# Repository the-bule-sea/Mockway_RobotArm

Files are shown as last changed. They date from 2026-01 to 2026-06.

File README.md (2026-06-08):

<div align="center">
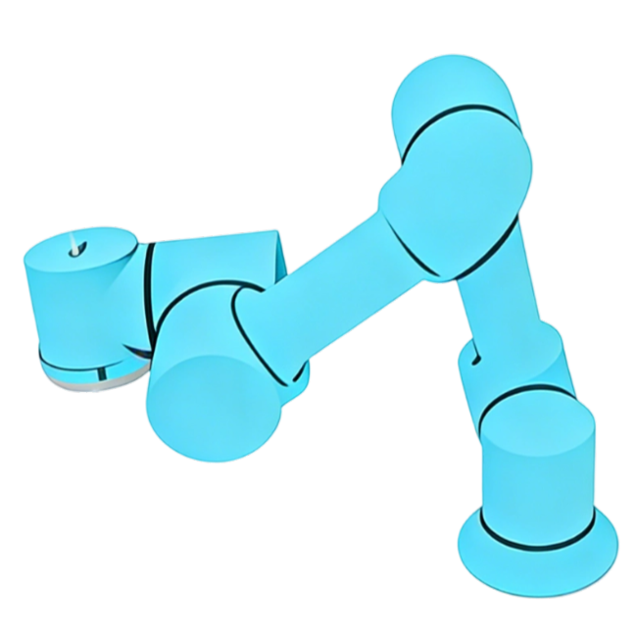
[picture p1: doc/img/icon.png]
  

  # 牧卫机器人

  开源六轴协作机械臂系统，包含机械结构、电路和软件

</div>

**中文 | [English](README_EN.md)**

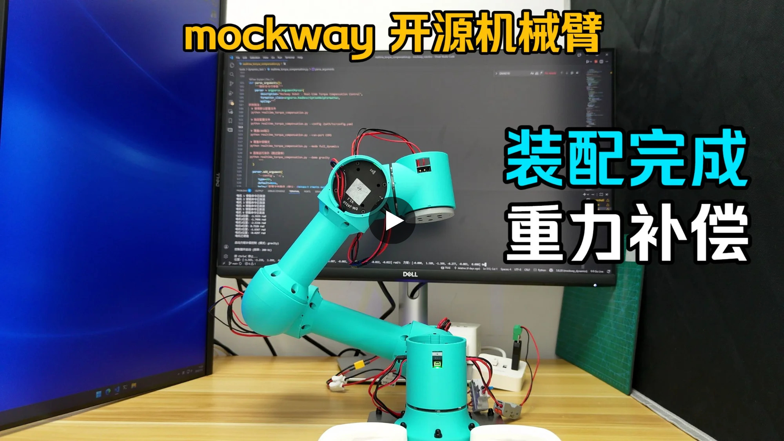
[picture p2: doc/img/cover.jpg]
robotarm_base (https://www.bilibili.com/video/BV1AxrbBWEjN/)


> 视频中测试程序为`tools/dynamics_test/real/inverse_dynamics_test.py`脚本
> 
> 运行后选择：1-重力补偿模式
> 
> 根据实际情况配置`tools/dynamics_test/dynamics_test.yaml`中串口等信息

CAN设备使用[维特USB-CAN模块](https://detail.tmall.com/item.htm?id=598670674373&skuId=4483773298672)，串口波特率921600，CAN总线波特率1M

## ⚙️ 机械结构

使用`JellyCAD`参数化建模，模型参数在`/jellycad_src`目录下，软件下载地址：[JellyCAD v0.3.10](https://github.com/Jelatine/JellyCAD/releases/tag/v0.3.10)

结构件可3D打印，已上传到[MakerWorld](https://makerworld.com.cn/zh/models/2037149-mockway-kai-yuan-liu-zhou-xie-zuo-ji-jie-bi#profileId-2273199)

makerworld (https://makerworld.com.cn/zh/models/2037149-mockway-kai-yuan-liu-zhou-xie-zuo-ji-jie-bi#profileId-2273199)

[组装指南.md](doc/组装指南.md)

## 🚀 程序运行

### 🎮 电机调试

单个电机运动调试和关节零点标定的界面

```bash
python tools/motor_gui/motor_gui.py
```

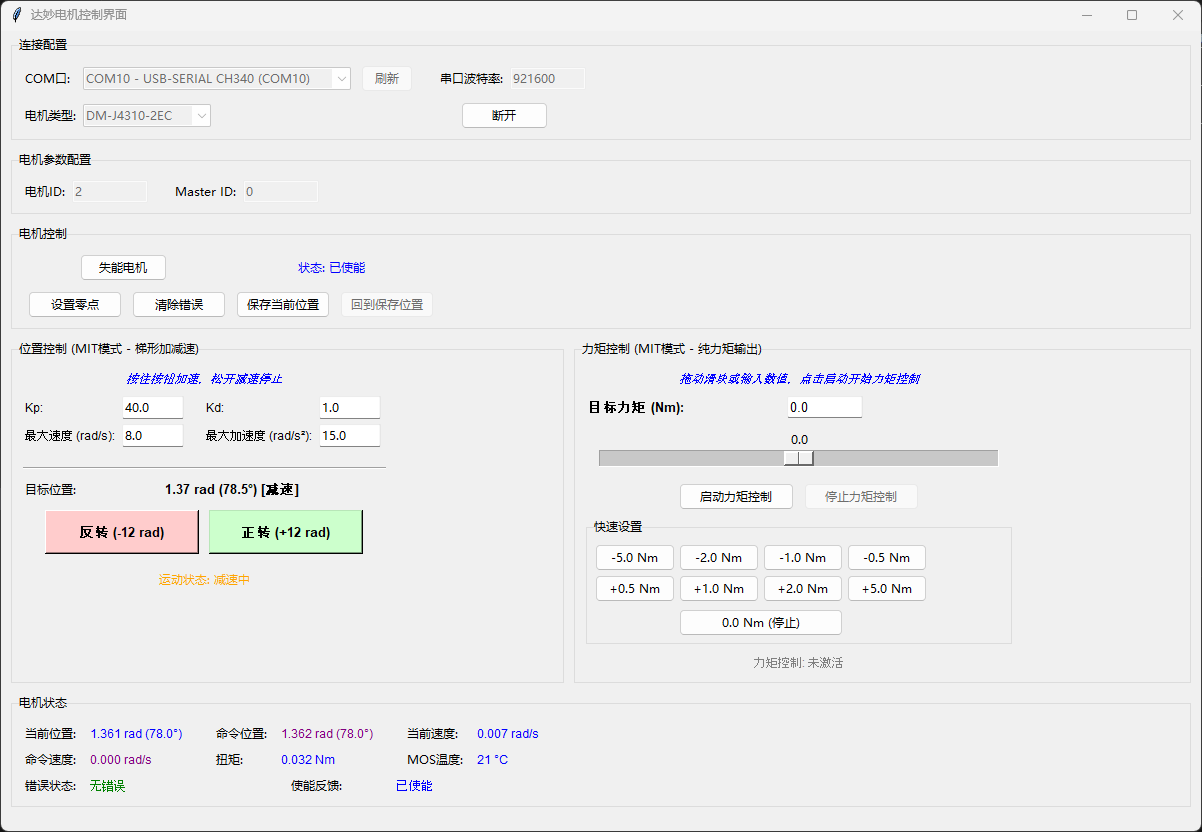
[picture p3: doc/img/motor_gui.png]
motor_gui


### ⚡ 力矩补偿

```bash
python tools/dynamics_test/realtime_torque_compensation.py
```

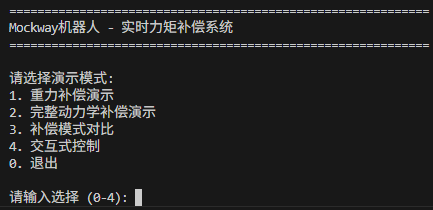
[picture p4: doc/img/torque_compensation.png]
torque_compensation


> 运行前请阅读下面 `⚠️ 注意事项`

### 🦾 运行MoveIt!

建议运行环境：

- Ubuntu 24.04
- ROS2 Jazzy + MoveIt!

1. 创建工作空间

```bash
mkdir -p ~/mockway_ws/src
cd ~/mockway_ws/src
```

2. 克隆mockway_robotics仓库

```bash
git clone https://github.com/Jelatine/mockway_robotics.git
```

3. 编译工作空间

```bash
cd ~/mockway_ws
rosdep install --from-paths src/mockway_robotics/moveit_mockway_config/ --ignore-src -r -y
colcon build --symlink-install --packages-select moveit_mockway_config
```
4. 配置环境变量

```bash
source ~/mockway_ws/install/setup.bash
```

5. 启动程序

```bash
ros2 launch moveit_mockway_config demo.launch.py use_mock_hardware:=true
```
**moveit, MujoCo联调**
```
ros2 launch mockway_mujoco_bridge mujoco_moveit launch.py use_sim_time:=false

```
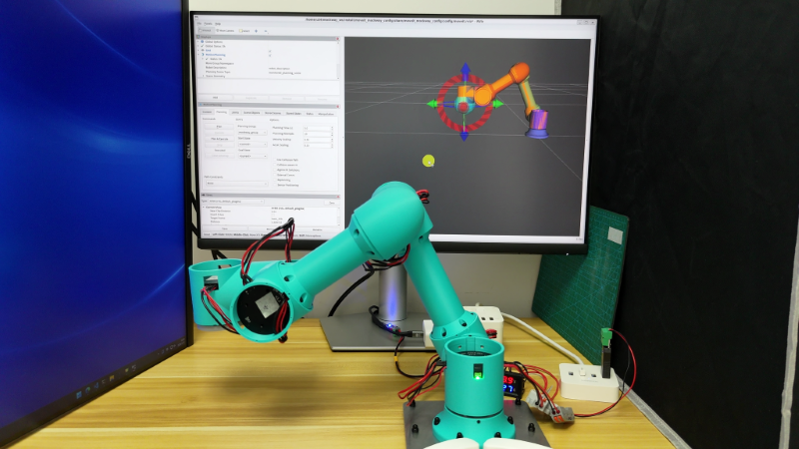
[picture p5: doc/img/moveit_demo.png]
moveit_demo


### 🖥️ 完整程序

1. 安装`lua`

```bash
sudo apt install liblua5.4-dev
```

2. 构建`mockway_bringup`

```bash
cd ~/mockway_ws
rosdep install --from-paths src/mockway_robotics/ --ignore-src -r -y
colcon build --symlink-install --packages-select mockway_bringup
```
3. 如果需要浏览器前端，再单独构建`mockway_lua_moveit`的 UI

```bash
cd ~/mockway_ws/src/mockway_robotics/mockway_lua_moveit/ui
npm install
npm run build
```

或在 colcon 构建时显式开启：

```bash
cd ~/mockway_ws
colcon build --symlink-install --packages-select mockway_lua_moveit --cmake-args -DBUILD_FRONTEND=ON
```

4. 启动程序

```bash
# 启动 move_group + servo ,仿真：use_mock_hardware:=true
ros2 launch mockway_bringup bringup.launch.py use_mock_hardware:=true
# 浏览器打开前端：http://localhost:8080/
```

### 🦞 OpenClaw应用

[应用视频](https://www.bilibili.com/video/BV1hnAjz9ESU/)

1. 将[skill](mockway_lua_moveit\robot_skill.md)文件放到openclaw的workspace目录下
2. 对话时让大模型学习skill文件中的指令，以及机械臂控制器的IP地址(或主机名)
3. 用自然语言控制机械臂，如：直线向上移动10厘米

## 📦 物料清单

详细的物料清单请查看：[BOM.md](doc/BOM.md)

复刻成本约4.2k（电机≈4k，打印件≈20，USB2CAN≈73，电源≈100，螺丝及工具<40）

## 🔌 电气连接

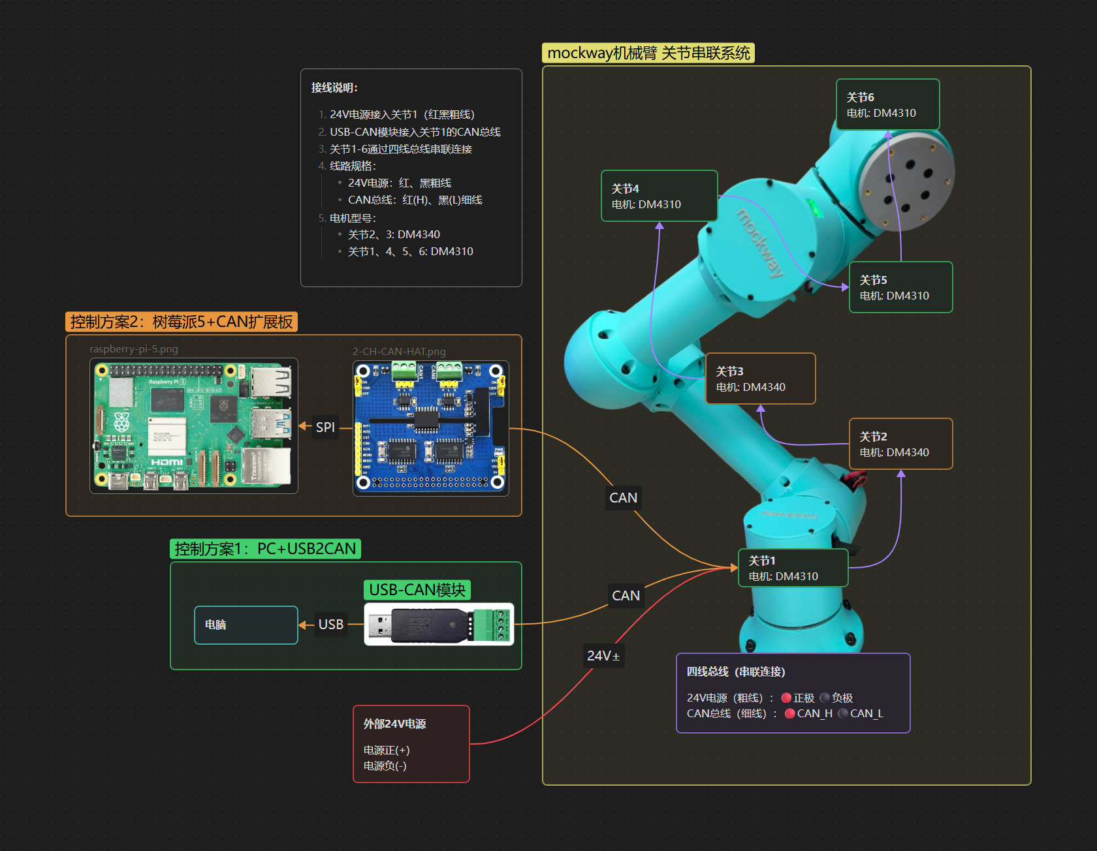
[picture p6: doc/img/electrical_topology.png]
electrical_topology


## ⚠️ 注意事项

**重要提示：力矩模式如果前期准备没做好容易发生飞车（失控）现象，请务必按照以下步骤操作。**

### 1. 结构匹配

确保机械结构与URDF模型一致。GitHub仓库最新版本已包含所有必需的结构件。

### 2. 关节零点标定

使用电机调试界面标定各关节零点位置，零点姿态需参考URDF定义。

```bash
python tools/motor_gui/motor_gui.py
```

calibrate_joint

### 3. 力矩值验证

在代码中注释掉`controller.enable_motors()`，先运行程序观察计算的力矩值是否正常。有条件的话，建议先运行一次位置模式，对比实际力矩与算法计算力矩的差异是否较小。

### 4. 重力补偿测试

初次测试时：
- 使用模式1（重力补偿模式）进行测试
- 增加电机阻尼参数：设置`mit_params.kd = 1`

### 5. 结构件打印

3D打印结构件时注意：
- 提高填充百分比（建议≥40%）
- 使用螺旋体（Gyroid）填充图案，以提高强度和减轻重量

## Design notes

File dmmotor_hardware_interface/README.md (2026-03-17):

# DM Motor Hardware Interface for ROS2 Control

ROS2 Control hardware interface plugin for DM motors (DM-J4310-2EC and DM4340) supporting multiple CAN interfaces.

## TODO

**fix:**

与move_group同时启动时，会出现 servo_node 等待 robot state update 的问题。

一直打印提示：`[servo_node]: Waiting to receive robot state update. `

参考：

[generic_system.hpp](https://github.com/ros-controls/ros2_control/blob/jazzy/hardware_interface/include/mock_components/generic_system.hpp)

[generic_system.cpp](https://github.com/ros-controls/ros2_control/blob/jazzy/hardware_interface/src/mock_components/generic_system.cpp)

[franka_hardware](https://github.com/frankarobotics/franka_ros2/blob/jazzy/franka_hardware/include/franka_hardware/franka_hardware_interface.hpp)

## Features

- Support for DM-J4310-2EC and DM4340 motors
- MIT control mode for smooth position/velocity control
- **Multiple CAN interface support:**
  - SocketCAN (Linux native CAN interface)
  - USB-CAN adapter (WitMotion USB-CAN and compatible devices)
- Real-time motor state feedback (position, velocity, torque, temperature)
- Configurable per-joint motor parameters

## Motor Configuration

### Joint Assignment
- Joint 1 (J1): DM-J4310-2EC
- Joint 2 (J2): DM4340
- Joint 3 (J3): DM4340
- Joint 4 (J4): DM-J4310-2EC
- Joint 5 (J5): DM-J4310-2EC
- Joint 6 (J6): DM-J4310-2EC

### Motor Parameters

**DM-J4310-2EC:**
- Max Position: ±12.5 rad
- Max Velocity: 30.0 rad/s
- Max Torque: 10.0 Nm

**DM4340:**
- Max Position: ±12.5 rad
- Max Velocity: 8.0 rad/s
- Max Torque: 28.0 Nm

## Prerequisites

Choose one of the following CAN interface options:

### Option 1: SocketCAN (Linux Native CAN)

#### 1.1 Install SocketCAN utilities

```bash
sudo apt-get update
sudo apt-get install can-utils
```

#### 1.2 Configure CAN Interface

Create a script to configure the CAN interface (e.g., `/etc/systemd/system/can-setup.sh`):

```bash
#!/bin/bash
# Setup CAN interface
sudo ip link set can0 type can bitrate 1000000
sudo ip link set up can0
```

Make it executable:
```bash
chmod +x /etc/systemd/system/can-setup.sh
```

To automatically setup CAN on boot, create a systemd service (`/etc/systemd/system/can-setup.service`):

```ini
[Unit]
Description=Setup CAN interface
After=network.target

[Service]
Type=oneshot
ExecStart=/etc/systemd/system/can-setup.sh
RemainAfterExit=yes

[Install]
WantedBy=multi-user.target
```

Enable the service:
```bash
sudo systemctl daemon-reload
sudo systemctl enable can-setup.service
sudo systemctl start can-setup.service
```

#### 1.3 Verify CAN Interface

```bash
# Check if CAN interface is up
ip link show can0

# Monitor CAN traffic
candump can0

# Send test frame
cansend can0 123#DEADBEEF
```

### Option 2: USB-CAN Adapter (WitMotion and Compatible)

#### 2.1 Connect USB-CAN Adapter

Connect your USB-CAN adapter to the computer. The adapter should appear as a serial device.

#### 2.2 Find Serial Port

```bash
# List available serial ports
ls /dev/ttyUSB* /dev/ttyACM*

# Or use dmesg to see the device
dmesg | grep tty
```

Common ports:
- `/dev/ttyUSB0` - Most USB-serial adapters
- `/dev/ttyACM0` - Some USB-CDC adapters
- `COM3`, `COM4`, etc. - Windows (not officially supported yet)

#### 2.3 Set Serial Port Permissions

Add your user to the `dialout` group to access serial ports:

```bash
sudo usermod -a -G dialout $USER
```

Log out and log back in for changes to take effect.

Alternatively, create a udev rule (`/etc/udev/rules.d/99-usb-can.rules`):

```
# WitMotion USB-CAN adapter
SUBSYSTEM=="tty", ATTRS{idVendor}=="1a86", ATTRS{idProduct}=="7523", MODE="0666", GROUP="dialout"
```

Reload udev rules:
```bash
sudo udevadm control --reload-rules
sudo udevadm trigger
```

#### 2.4 Test USB-CAN Connection

You can test the USB-CAN adapter using the Python driver:

```bash
cd ~/ws/mockway_robotics/tools/motor_gui
python3 dm_motor_driver.py
```

Or use a serial terminal:
```bash
# Install minicom if not already installed
sudo apt-get install minicom

# Connect to the adapter (adjust port and baudrate)
minicom -D /dev/ttyUSB0 -b 921600

# Send AT command to test
AT+AT
# Should receive: OK
```

## Building

```bash
cd ~/ws/mockway_robotics
colcon build --packages-select dmmotor_hardware_interface
source install/setup.bash
```

## Configuration

The hardware interface is configured in the URDF/xacro file (`moveit_mockway_config/config/mockway_description.ros2_control.xacro`).

### Hardware Parameters

#### For SocketCAN

```xml
<hardware>
    <plugin>dmmotor_hardware_interface/DMMototHardwareInterface</plugin>
    <param name="can_interface_type">socketcan</param>  <!-- Optional, default is socketcan -->
    <param name="can_port">can0</param>
    <param name="can_baudrate">1000000</param>
    <param name="position_kp">40.0</param>
    <param name="position_kd">1.0</param>
</hardware>
```

#### For USB-CAN Adapter

```xml
<hardware>
    <plugin>dmmotor_hardware_interface/DMMototHardwareInterface</plugin>
    <param name="can_interface_type">usb_can</param>
    <param name="can_port">/dev/ttyUSB0</param>           <!-- Serial port -->
    <param name="serial_baudrate">921600</param>          <!-- Serial baudrate, default: 921600 -->
    <param name="can_baudrate">1000000</param>            <!-- CAN baudrate -->
    <param name="position_kp">40.0</param>
    <param name="position_kd">1.0</param>
</hardware>
```

**Parameter Reference:**
- `can_interface_type`: Interface type - `socketcan` or `usb_can` (default: `socketcan`)
- `can_port`: For SocketCAN: interface name (e.g., `can0`). For USB-CAN: serial port (e.g., `/dev/ttyUSB0`)
- `can_baudrate`: CAN bus baudrate in bps (typically 1000000 for 1 Mbps)
- `serial_baudrate`: (USB-CAN only) Serial port baudrate (default: 921600)
- `position_kp`: Position control proportional gain [0-500]
- `position_kd`: Position control derivative gain [0-5]

### Joint Parameters

For each joint, specify:
- `motor_id`: CAN ID of the motor (1-127)
- `master_id`: CAN ID for receiving feedback (typically 0)
- `motor_type`: Either `DM_J4310_2EC` or `DM4340`

Example:
```xml
<joint name="joint1">
    <command_interface name="position"/>
    <state_interface name="position"/>
    <state_interface name="velocity"/>
    <param name="motor_id">1</param>
    <param name="master_id">0</param>
    <param name="motor_type">DM_J4310_2EC</param>
</joint>
```

## Usage

### Starting the Hardware Interface

The hardware interface is automatically loaded by ros2_control when you launch MoveIt:

```bash
ros2 launch moveit_mockway_config demo.launch.py
```

### Motor Control Modes

The hardware interface uses **MIT control mode** for position control:

```
torque = kp * (p_cmd - p_actual) + kd * (v_cmd - v_actual)
```

Control parameters (`position_kp` and `position_kd`) can be tuned in the xacro file.

### Monitoring Motor Status

```bash
# Check joint states
ros2 topic echo /joint_states

# Monitor controller status
ros2 control list_controllers

# View hardware component status
ros2 control list_hardware_components
```

## Troubleshooting

### CAN Interface Issues

#### SocketCAN Issues

**Problem:** `Failed to open CAN interface can0`

**Solutions:**
1. Check if CAN interface exists: `ip link show can0`
2. Bring up the interface: `sudo ip link set up can0`
3. Verify bitrate: `ip -details link show can0`
4. Check CAN hardware connection

#### USB-CAN Issues

**Problem:** `Failed to open serial port /dev/ttyUSB0`

**Solutions:**
1. Check if device exists: `ls -l /dev/ttyUSB0`
2. Verify USB connection: `dmesg | tail`
3. Check permissions: `sudo usermod -a -G dialout $USER` (log out/in after)
4. Try different USB ports
5. Check USB cable quality

**Problem:** `Warning: Failed to enter AT mode`

**Solutions:**
1. Verify serial baudrate is correct (typically 921600)
2. Try power-cycling the USB-CAN adapter
3. Check if adapter is in correct mode
4. Some adapters may work without AT mode confirmation - check if CAN communication works

**Problem:** `Permission denied when accessing serial port`

**Solutions:**
1. Add user to dialout group: `sudo usermod -a -G dialout $USER`
2. Log out and log back in
3. Or use udev rules (see USB-CAN setup section)
4. Temporary fix: `sudo chmod 666 /dev/ttyUSB0`

**Problem:** `No feedback from motors`

**Solutions:**
1. Check CAN wiring and termination resistors (120Ω at both ends)
2. Verify motor power supply
3. Monitor CAN bus: `candump can0`
4. Check motor IDs match configuration
5. Ensure motors are properly enabled

**Problem:** `Motors not responding to commands`

**Solutions:**
1. Verify motors are enabled (check error codes)
2. Check motor ID configuration
3. Ensure CAN baudrate matches (1 Mbps)
4. Verify MIT control parameters are reasonable

### Error Codes

Motor error codes are reported in feedback:
- `0x0`: Disabled
- `0x1`: Enabled (normal operation)
- `0x8`: Over-voltage
- `0x9`: Under-voltage
- `0xA`: Over-current
- `0xB`: MOS over-temperature
- `0xC`: Coil over-temperature
- `0xD`: Communication loss
- `0xE`: Overload

## Safety Notes

1. **Emergency Stop**: Always have an emergency stop mechanism
2. **Workspace Limits**: Ensure joint limits are properly configured
3. **Temperature Monitoring**: Monitor motor temperatures during operation
4. **Power Supply**: Use appropriate power supply (check motor specifications)
5. **Initial Testing**: Test with low velocities and accelerations initially

## Development and Debugging

### Enable Debug Logging

```bash
ros2 launch moveit_mockway_config demo.launch.py --ros-args --log-level dmmotor_hardware_interface:=debug
```

### Test Individual Motors

Use the Python driver for testing:

```bash
cd ~/ws/mockway_robotics/tools/motor_gui
python3 dm_motor_driver.py
```

## References

- [ROS2 Control Documentation](https://control.ros.org/)
- [SocketCAN Documentation](https://www.kernel.org/doc/Documentation/networking/can.txt)
- DM Motor Manual (refer to manufacturer documentation)

## License

MIT License - Copyright (c) 2025 Mockway Robotics

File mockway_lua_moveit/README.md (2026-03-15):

# mockway_lua_moveit

使用 [sol2](https://github.com/ThePhD/sol2) 将 MoveIt 和 MoveIt Servo 封装为 Lua API，通过执行 Lua 脚本控制机械臂。

## 单位约定

> 所有 Lua API 输入/输出统一使用以下单位：
>
> | 量 | 单位 |
> |---|---|
> | 位置（x, y, z） | **mm**（毫米） |
> | 角度（关节、RPY、旋转增量） | **deg**（度） |
> | 线速度（Servo） | **mm/s** |
> | 角速度（Servo） | **deg/s** |
> | 插值步长（直线运动） | **mm**，默认 10 |

## 前置条件

运行前需启动以下节点之一：

| 场景 | 启动命令 |
|---|---|
| 仅 MoveIt（PTP / 直线运动） | `ros2 launch moveit_mockway_config demo.launch.py` |
| 仅 Servo（手动点动） | `ros2 launch mockway_moveit_servo servo.launch.py` |
| MoveIt + Servo | `ros2 launch mockway_bringup mockway.launch.py` |

## 快速启动

```bash
# 使用内置演示脚本（脚本名不含 .lua）
ros2 launch mockway_lua_moveit lua_moveit.launch.py script:=demo_ptp
ros2 launch mockway_lua_moveit lua_moveit.launch.py script:=demo_linear
ros2 launch mockway_lua_moveit lua_moveit.launch.py script:=demo_joint_servo
ros2 launch mockway_lua_moveit lua_moveit.launch.py script:=demo_cartesian_servo

# 使用自定义脚本
ros2 launch mockway_lua_moveit lua_moveit.launch.py script_path:=/path/to/my_script.lua
```

### launch 参数

| 参数 | 默认值 | 说明 |
|---|---|---|
| `script` | `demo_joint_servo` | 内置 `lua/` 目录下的脚本名（不含 `.lua`） |
| `script_path` | `""` | 脚本绝对路径，优先级高于 `script` |
| `planning_group` | `mockway_group` | MoveIt 规划组 |
| `ee_frame` | `link6` | 末端执行器坐标系 |
| `base_frame` | `base_link` | 基坐标系 |
| `launch_servo` | `false` | 是否同时启动 servo_node |

---

## Lua API 参考

在 Lua 脚本中，机器人接口通过全局表 `robot` 访问。
辅助封装通过 `local api = require("robot_api")` 加载。

### 一、Servo 手动点动

> 需要 servo_node 运行。发布消息后立即返回（非阻塞）。

#### `robot.switch_servo_mode(mode)` → bool

切换 Servo 命令类型。

| 参数 | 类型 | 说明 |
|---|---|---|
| `mode` | string | `"joint_jog"` 或 `"twist"` |

```lua
robot.switch_servo_mode("joint_jog")
robot.switch_servo_mode("twist")
```

#### `robot.servo_joint(name_or_index, velocity)`

单关节速度点动。

| 参数 | 类型 | 说明 |
|---|---|---|
| `name_or_index` | string \| int | 关节名 `"joint1"`～`"joint6"` 或索引 `1`～`6` |
| `velocity` | number | 目标速度，单位 **deg/s** |

```lua
robot.servo_joint(1, 20.0)          -- joint1 以 20 deg/s 点动
robot.servo_joint("joint3", -15.0)  -- joint3 反向点动
```

#### `robot.servo_joints(velocities)`

六轴同时速度点动。

| 参数 | 类型 | 说明 |
|---|---|---|
| `velocities` | table | `{v1, v2, v3, v4, v5, v6}`，单位 **deg/s** |

```lua
robot.servo_joints({0.0, 0.0, 0.0, 20.0, 20.0, 0.0})
```

#### `robot.servo_cartesian(vx, vy, vz, rx, ry, rz [, frame_id])`

笛卡尔空间速度点动（Twist）。

| 参数 | 类型 | 说明 |
|---|---|---|
| `vx/vy/vz` | number | 线速度，单位 **mm/s** |
| `rx/ry/rz` | number | 角速度，单位 **deg/s** |
| `frame_id` | string | 参考坐标系，默认 `base_link` |

```lua
robot.servo_cartesian(100, 0, 0,  0, 0, 0)              -- 沿基坐标系 X 轴前进 100mm/s
robot.servo_cartesian(0, 0, 100,  0, 0, 0, robot.ee_frame)  -- 沿末端 Z 轴移动
```

#### `robot.servo_stop()`

向两个 topic 发布零速，停止 Servo 运动。

```lua
robot.servo_stop()
```

---

### 二、MoveIt 点到点运动（PTP）

> 需要 move_group 运行。阻塞直到运动完成，返回 bool。

#### `robot.move_to_named(name)` → bool

运动到 SRDF 中定义的命名状态。

```lua
robot.move_to_named("home")
robot.move_to_named("ready")
```

#### `robot.move_to_joints(positions)` → bool

按关节角度做 PTP 运动。

| 参数 | 类型 | 说明 |
|---|---|---|
| `positions` | table | `{j1, j2, j3, j4, j5, j6}`，单位 **deg** |

```lua
robot.move_to_joints({0, -45, -90, 60, 90, 0})
```

#### `robot.move_to_pose(x, y, z, qx, qy, qz, qw)` → bool

按末端位姿做 PTP 运动（四元数）。x/y/z 单位 **mm**。

```lua
robot.move_to_pose(300, 0, 350,  1.0, 0.0, 0.0, 0.0)
```

#### `robot.move_to_pose_rpy(x, y, z, roll, pitch, yaw)` → bool

按末端位姿做 PTP 运动（RPY 欧拉角）。x/y/z 单位 **mm**，角度单位 **deg**。

```lua
robot.move_to_pose_rpy(250, 100, 300,  180, 0, 0)
```

---

### 三、MoveIt 直线运动（Linear）

> 需要 move_group 运行。通过 `computeCartesianPath` 实现，阻塞直到运动完成，返回 bool。
> 规划成功率 < 90% 时取消执行并返回 false。

#### `robot.move_linear(x, y, z, qx, qy, qz, qw [, step [, min_fraction]])` → bool

绝对位姿直线运动（四元数）。x/y/z 单位 **mm**。

| 参数 | 类型 | 默认值 | 说明 |
|---|---|---|---|
| `step` | number | `10` | 插值步长，单位 **mm** |
| `min_fraction` | number | `0.9` | 最小规划完成比例 |

```lua
robot.move_linear(300, 0, 400,  1.0, 0.0, 0.0, 0.0)
robot.move_linear(300, 0, 400,  1.0, 0.0, 0.0, 0.0,  5)        -- 精细步长 5mm
robot.move_linear(300, 0, 400,  1.0, 0.0, 0.0, 0.0,  10, 0.95) -- 要求 95% 完成
```

#### `robot.move_linear_rpy(x, y, z, roll, pitch, yaw [, step])` → bool

绝对位姿直线运动（RPY 欧拉角）。x/y/z 单位 **mm**，角度 **deg**，step 单位 **mm**。

```lua
robot.move_linear_rpy(300, 0, 400,  180, 0, 0)
```

#### `robot.move_linear_relative(dx, dy, dz, drx, dry, drz [, step])` → bool

相对当前末端位置的增量直线运动。

| 参数 | 类型 | 说明 |
|---|---|---|
| `dx/dy/dz` | number | 位置偏移，单位 **mm** |
| `drx/dry/drz` | number | 姿态偏移（RPY 增量），单位 **deg** |
| `step` | number | 插值步长，单位 **mm**，默认 10 |

```lua
robot.move_linear_relative(0.0,  0.0, 50.0,  0.0, 0.0, 0.0)       -- 沿 Z 轴上升 50mm
robot.move_linear_relative(30.0, 0.0, 0.0,   0.0, 0.0, 10.0)       -- X 前移 30mm + Z 轴转 10°
```

---

### 四、规划参数

> 需要 move_group 运行。设置后对后续所有规划生效。

#### `robot.set_velocity_scaling(factor)`

设置最大速度缩放系数，范围 `[0.01, 1.0]`。

```lua
robot.set_velocity_scaling(0.3)   -- 30% 最大速度
```

#### `robot.set_acceleration_scaling(factor)`

设置最大加速度缩放系数，范围 `[0.01, 1.0]`。

```lua
robot.set_acceleration_scaling(0.1)
```

#### `robot.set_planning_time(seconds)`

设置规划超时时间。

```lua
robot.set_planning_time(5.0)
```

#### `robot.set_planner(planner_id)`

切换运动规划器。

```lua
robot.set_planner("RRTConnect")
robot.set_planner("LIN")   -- Pilz 直线规划器
```

---

### 五、状态查询

> 需要 move_group 运行。

#### `robot.get_joint_positions()` → table

返回当前关节角度，单位 **deg**。

```lua
local j = robot.get_joint_positions()
-- j[1]~j[6]，单位 deg
print(j[1])
```

#### `robot.get_current_pose()` → table

返回当前末端位姿（四元数）。x/y/z 单位 **mm**。

```lua
local p = robot.get_current_pose()
-- p.x, p.y, p.z        位置，单位 mm
-- p.qx, p.qy, p.qz, p.qw  姿态四元数
```

#### `robot.get_current_rpy()` → table

返回当前末端姿态（RPY 欧拉角），单位 **deg**。

```lua
local r = robot.get_current_rpy()
-- r.roll, r.pitch, r.yaw，单位 deg
```

---

### 六、工具函数

#### `robot.sleep(seconds)`

暂停执行。

```lua
robot.sleep(0.5)
```

#### `robot.log(msg)` / `robot.log_warn(msg)` / `robot.log_error(msg)`

输出 ROS 日志。

```lua
robot.log("运动完成")
robot.log_warn("速度过高")
robot.log_error("规划失败")
```

#### `robot.ok()` → bool

返回 ROS 节点是否仍在运行，可用于循环退出条件。

```lua
while robot.ok() do
  robot.servo_joint(1, 20.0)
  robot.sleep(0.02)
end
```

#### `deg2rad(deg)` / `rad2deg(rad)`

角度与弧度互转（全局函数，备用）。

```lua
deg2rad(90)   -- → 1.5708
rad2deg(1.57) -- → 89.95
```

#### 常量

| 变量 | 说明 |
|---|---|
| `robot.ee_frame` | 末端执行器坐标系名，默认 `"link6"` |
| `robot.base_frame` | 基坐标系名，默认 `"base_link"` |
| `robot.planning_group` | 规划组名，默认 `"mockway_group"` |
| `robot.joint_names` | 关节名列表 `{"joint1", ..., "joint6"}` |

---

## robot_api 辅助模块

`require("robot_api")` 提供基于 `robot.*` 的高层封装：

#### `api.print_joints()`

以度数打印当前六轴关节角。

#### `api.print_pose()`

打印当前末端位置（mm）和 RPY 姿态（deg）。

#### `api.jog_joint(idx, velocity, duration)`

关节点动指定时长后自动停止。velocity 单位 **deg/s**。

```lua
api.jog_joint(3, 20.0, 1.5)   -- joint3 以 20 deg/s 点动 1.5 秒
```

#### `api.jog_cartesian(vx, vy, vz, rx, ry, rz, duration [, frame])`

笛卡尔点动指定时长后自动停止。线速度单位 **mm/s**，角速度 **deg/s**。

```lua
api.jog_cartesian(100, 0, 0,  0, 0, 0,  1.5)                   -- 沿 X 轴移动 1.5 秒
api.jog_cartesian(0, 0, 100,  0, 0, 0,  1.0, robot.ee_frame)    -- 末端坐标系
```

#### `api.joints_deg(a1, a2, a3, a4, a5, a6)` → table

度数输入，返回关节目标表，用于 `robot.move_to_joints()`。

```lua
robot.move_to_joints(api.joints_deg(0, -45, -90, 60, 90, 0))
-- 与以下写法等价：
robot.move_to_joints({0, -45, -90, 60, 90, 0})
```

#### `api.move_linear_waypoints(waypoints)` → bool

多航点直线折线运动，逐段执行 `robot.move_linear()`。x/y/z 单位 **mm**。

```lua
local path = {
  {300, 0.0, 400,  1.0, 0.0, 0.0, 0.0},
  {300, 100, 400,  1.0, 0.0, 0.0, 0.0},
  {300, 100, 350,  1.0, 0.0, 0.0, 0.0},
}
api.move_linear_waypoints(path)
```

---

## 内置演示脚本

| 脚本 | 功能 | 所需节点 |
|---|---|---|
| `demo_joint_servo.lua` | 逐轴 / 多轴关节点动演示（deg/s） | servo_node |
| `demo_cartesian_servo.lua` | 笛卡尔平移（mm/s）/ 旋转（deg/s）/ 组合点动 | servo_node |
| `demo_ptp.lua` | PTP 命名状态 / 关节角（deg）/ 位姿目标（mm）/ 速度缩放 | move_group |
| `demo_linear.lua` | 绝对 / 相对 / 多航点直线运动（mm）/ 矩形轨迹 | move_group |

---

## 编写自定义脚本

```lua
-- my_script.lua
local api = require("robot_api")

-- 初始参数
robot.set_velocity_scaling(0.3)
robot.set_acceleration_scaling(0.1)

-- 回 home
assert(robot.move_to_named("home"), "回 home 失败")

-- 直线上升 50mm
robot.move_linear_relative(0, 0, 50,  0, 0, 0)

-- 打印状态
api.print_pose()
```

启动：

```bash
ros2 launch mockway_lua_moveit lua_moveit.launch.py \
  script_path:=/path/to/my_script.lua
```

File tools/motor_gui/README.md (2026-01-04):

# 达妙电机 DM-J4310-2EC 图形控制界面

## 简介

这是一个用于控制达妙电机 DM-J4310-2EC 的图形化控制界面，通过维特 USB-CAN 适配器进行 CAN 通信。

## 功能特性

- 通过串口连接维特 USB-CAN 适配器
- **支持多种电机型号**（DM-J4310-2EC、DM4340）
- 支持 MIT 控制模式
- 支持梯形加减速运动控制
- 实时显示电机状态（位置、速度、扭矩、温度等）
- 图形化参数配置界面

## 系统要求

- Python 3.7+
- 维特 USB-CAN 适配器
- 达妙电机（支持以下型号）：
  - DM-J4310-2EC（最大扭矩 10 Nm，最大速度 30 rad/s）
  - DM4340（最大扭矩 28 Nm，最大速度 10 rad/s）

## 支持的电机型号对比

| 参数 | DM-J4310-2EC | DM4340 |
|---|---|---|
| 最大位置 (MIT模式) | ±12.5 rad | ±12.5 rad |
| **最大速度** | **30 rad/s** | **10 rad/s** |
| **最大扭矩** | **10 Nm** | **28 Nm** |
| 最大Kp | 500 | 500 |
| 最大Kd | 5 | 5 |
| 特性 | 高速、轻载 | 大扭矩、重载 |

**选择建议**：
- **DM-J4310-2EC**：高速度（30 rad/s）、中等扭矩（10 Nm），适合轻载、高速场景（如小型机械臂、云台、快速运动关节）
- **DM4340**：大扭矩（28 Nm）、低速度（10 rad/s），适合重载、大扭矩场景（如重载机械臂、移动机器人、需要大力矩的关节）

## 安装依赖

### 方式一：使用 pip（推荐用于已有 Python 环境）

在 `tools/motor_gui` 目录下运行：

```bash
pip install -r requirements.txt
```

### 方式二：使用 conda（推荐用于隔离环境）

如果您使用 Anaconda 或 Miniconda，可以创建独立的 conda 环境：

```bash
# 创建名为 motor_gui 的 conda 环境（Python 3.9）
conda create -n motor_gui python=3.9 -y

# 激活环境
conda activate motor_gui

# 安装 pyserial
conda install -c conda-forge pyserial -y

# 或者使用 pip 安装（在 conda 环境中）
pip install -r requirements.txt

# 运行程序
python motor_gui.py

# 使用完毕后退出环境
# conda deactivate
```

**注意**: conda 环境中的 Python 通常已经包含 tkinter，无需额外安装。

### 依赖说明

- **pyserial**: 用于串口通信，与 USB-CAN 适配器进行数据交互
- **tkinter**: Python 内置 GUI 库（某些 Linux 发行版需要单独安装）

### Linux 系统额外安装

在某些 Linux 发行版上，需要单独安装 tkinter：

**Ubuntu/Debian:**
```bash
sudo apt-get install python3-tk
```

**Fedora:**
```bash
sudo dnf install python3-tkinter
```

**Arch Linux:**
```bash
sudo pacman -S tk
```

## 快速开始

### 使用 conda 环境（推荐）

```bash
# 1. 进入项目目录
cd /path/to/mockway_robotics/tools/motor_gui

# 2. 创建并激活 conda 环境
conda create -n motor_gui python=3.9 -y
conda activate motor_gui

# 3. 安装依赖
conda install -c conda-forge pyserial -y

# 4. 启动图形界面
python motor_gui.py

# 5. 下次使用时，只需激活环境即可
# conda activate motor_gui
# python motor_gui.py
```

### 使用 pip 环境

```bash
# 1. 进入项目目录
cd /path/to/mockway_robotics/tools/motor_gui

# 2. （可选）创建虚拟环境
python -m venv venv
source venv/bin/activate  # Linux/macOS
# 或
venv\Scripts\activate     # Windows

# 3. 安装依赖
pip install -r requirements.txt

# 4. 启动图形界面
python motor_gui.py
```

## 使用方法

### 启动图形界面

```bash
python motor_gui.py
```

### 配置参数

1. **连接配置**
   - COM口：设置串口端口号（Windows: COM9, Linux: /dev/ttyUSB0）
   - 串口波特率：默认 921600
   - **电机类型**：选择电机型号（DM-J4310-2EC 或 DM4340）
     - DM-J4310-2EC: 最大扭矩 10 Nm，最大速度 30 rad/s（高速、轻载）
     - DM4340: 最大扭矩 28 Nm，最大速度 10 rad/s（大扭矩、重载）
   - 点击"连接"按钮建立连接

2. **电机参数配置**
   - 电机ID：CAN 总线上的电机 ID（默认 2）
   - Master ID：主机 ID，用于接收反馈帧（默认 0）
   - Kp：位置比例系数（默认 40.0）
   - Kd：位置微分系数（默认 1.0）
   - 最大速度：梯形加减速的最大速度（默认 8.0 rad/s）
   - 最大加速度：梯形加减速的最大加速度（默认 15.0 rad/s²）

3. **电机控制**
   - 连接后点击"使能电机"启用电机
   - 使用"正转"和"反转"按钮控制电机运动
   - 按住按钮：电机加速到目标位置
   - 松开按钮：电机开始减速停止

### 串口设置说明

本程序通过串口与维特 USB-CAN 适配器通信：

- **Windows 平台**: 串口名称通常为 `COM3`, `COM4`, `COM9` 等
- **Linux 平台**: 串口名称通常为 `/dev/ttyUSB0`, `/dev/ttyUSB1` 等
- **macOS 平台**: 串口名称通常为 `/dev/tty.usbserial-XXXX` 或 `/dev/cu.usbserial-XXXX`

#### 查看可用串口

**Linux/macOS:**
```bash
ls /dev/tty*
# 或者
python -m serial.tools.list_ports
```

**Windows:**
在设备管理器中查看端口（COM 和 LPT）

#### Linux 串口权限设置

如果遇到权限问题，需要将当前用户添加到 dialout 组：

```bash
sudo usermod -a -G dialout $USER
```

然后注销并重新登录，或者运行：
```bash
newgrp dialout
```

## 文件说明

- `motor_gui.py`: 图形界面主程序
- `dm_motor_driver.py`: 电机驱动程序，包含 CAN 通信和电机控制逻辑
- `requirements.txt`: Python 依赖包列表
- `README.md`: 本说明文档

## 故障排除

### 无法打开串口

- 检查串口名称是否正确
- 检查 USB-CAN 适配器是否正确连接
- 检查串口权限（Linux 系统）
- 检查是否有其他程序正在占用串口

### 无法接收到电机反馈数据

- 检查 CAN 总线连接是否正常
- 检查电机 ID 和 Master ID 设置是否正确
- 检查电机电源是否正常
- 检查 CAN 波特率设置（默认 1000000）

### 电机不响应

- 确认电机已使能
- 检查电机错误状态
- 检查电机温度是否过高
- 检查电源电压是否正常

## 开发者信息

- 作者: Claude
- 日期: 2025-12-30
- 适用电机: 达妙 DM-J4310-2EC、DM4340
- 版本: v1.1 (新增多电机型号支持)

## 许可证

本项目仅供学习和研究使用。

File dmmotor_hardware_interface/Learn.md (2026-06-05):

Read [](file:///home/fu/Documents/001_code/mockway_ws/src/mockway_robotics/dmmotor_hardware_interface/src/dmmotor_hardware_interface.cpp)

## 代码详解 - 初学者版

我来用通俗易懂的方式解释这个代码。先从整体架构开始，然后逐个模块讲解。

---

### 🎯 这个代码是做什么的？

想象一下，你有一个 **6 自由度机械臂**，你想用电脑控制它动起来。这个代码就是 **电脑和机械臂之间的"翻译官"**：

```
电脑软件 (ROS2/MoveIt)
    ↓ 发送指令："关节1转到30度"
这个代码 (翻译官)
    ↓ 翻译成电机能懂的语言
电机 (达妙电机)
    ↓ 执行动作
机械臂动起来
```

---

### 🏗️ 整体架构（三层结构）

```
┌─────────────────────────────────────────────────────────┐
│  第1层：ROS2 Control 框架（上层）                          │
│  - controller_manager：管理所有控制器                      │
│  - JointTrajectoryController：轨迹规划                    │
│  - JointStateBroadcaster：发布关节状态                     │
└─────────────────────────────────────────────────────────┘
                          ↕ 标准接口
┌─────────────────────────────────────────────────────────┐
│  第2层：这个代码（中间层）                                  │
│  - 实现 hardware_interface::SystemInterface               │
│  - 接收上层指令，翻译成CAN命令                              │
│  - 读取电机反馈，报告给上层                                  │
└─────────────────────────────────────────────────────────┘
                          ↕ CAN总线
┌─────────────────────────────────────────────────────────┐
│  第3层：硬件层（底层）                                      │
│  - 达妙电机（DM4310, DM4340等）                            │
│  - SocketCAN 或 USB-CAN 适配器                            │
└─────────────────────────────────────────────────────────┘
```

---

### 📦 代码结构分解

#### **第1部分：类定义（第38-160行）**

```cpp
class DMMototHardwareInterface : public hardware_interface::SystemInterface
```

**类比**：这就像一个"电器适配器"，把 ROS2 的标准接口转换成达妙电机能懂的 CAN 协议。

**关键成员变量**：
```cpp
CanType can_type_;          // CAN接口类型（SocketCAN 或 USB-CAN）
int can_socket_;            // SocketCAN 的"文件句柄"
int serial_fd_;             // USB-CAN 串口的"文件句柄"
std::vector<DamiaoMotor> motors_;  // 电机列表
```

**电机结构体**（第102-116行）：
```cpp
struct DamiaoMotor {
    uint32_t can_id;      // 电机的"身份证号"（CAN ID）
    double position;       // 当前位置
    double velocity;       // 当前速度
    double effort;         // 当前力矩
    double cmd_position;   // 命令位置（想让它去哪）
    double kp, kd;         // 控制参数（PID中的P和D）
    double dir;            // 方向（+1或-1）
    bool is_simulated;     // 是否是仿真电机
};
```

---

#### **第2部分：生命周期函数（ROS2 Control 要求的）**

这些函数是 ROS2 Control 框架要求实现的，就像"标准接口"：

| 函数 | 作用 | 类比 |
|---|---|---|
| `on_init()` | 初始化，读取配置 | 开箱，看说明书 |
| `on_configure()` | 配置硬件，建立连接 | 插上电源，连上网线 |
| `on_activate()` | 激活，使能电机 | 按下"启动"按钮 |
| `on_deactivate()` | 停用，关闭电机 | 按下"停止"按钮 |
| `read()` | 读取电机状态 | 看仪表盘 |
| `write()` | 发送控制命令 | 踩油门/打方向盘 |

---

#### **第3部分：CAN 通信函数**

##### **3.1 SocketCAN 初始化（第444-472行）**

```cpp
bool DMMototHardwareInterface::init_can_socket() {
    // 1. 创建 socket（像打开一个"通信管道"）
    can_socket_ = socket(PF_CAN, SOCK_RAW, CAN_RAW);
    
    // 2. 绑定到 can0 接口（指定用哪个"管道"）
    struct ifreq ifr;
    strcpy(ifr.ifr_name, can_interface_.c_str());
    ioctl(can_socket_, SIOCGIFINDEX, &ifr);
    
    // 3. 设置为非阻塞模式（不等待，有数据就读）
    int flags = fcntl(can_socket_, F_GETFL, 0);
    fcntl(can_socket_, F_SETFL, flags | O_NONBLOCK);
}
```

**类比**：就像打开一个对讲机，调到指定频道（can0），然后设置"不等待回复"模式。

##### **3.2 USB-CAN 串口初始化（第483-568行）**

```cpp
bool DMMototHardwareInterface::init_usb_can_serial() {
    // 1. 打开串口（像打开一个"文件"）
    serial_fd_ = open(can_interface_.c_str(), O_RDWR | O_NOCTTY | O_NONBLOCK);
    
    // 2. 配置串口参数
    //    - 波特率：921600（通信速度）
    //    - 8N1：8位数据，无校验，1位停止位
    //    - 原始模式：不做任何处理
    
    // 3. 进入AT指令模式（维特适配器的特殊要求）
    enter_usb_can_at_mode();
}
```

**类比**：就像用一根特殊的USB线连接电脑和电机，需要设置好"通信规则"。

---

#### **第4部分：核心控制函数**

##### **4.1 使能/禁用电机（第828-844行）**

```cpp
void DMMototHardwareInterface::enable_motor(uint32_t can_id) {
    uint8_t enable_cmd[8] = {0xFF, 0xFF, 0xFF, 0xFF, 0xFF, 0xFF, 0xFF, 0xFC};
    send_can_frame(can_id, enable_cmd, 8);
}

void DMMototHardwareInterface::disable_motor(uint32_t can_id) {
    uint8_t disable_cmd[8] = {0xFF, 0xFF, 0xFF, 0xFF, 0xFF, 0xFF, 0xFF, 0xFD};
    send_can_frame(can_id, disable_cmd, 8);
}
```

**关键点**：
- `0xFC` = 使能命令（Enable）
- `0xFD` = 禁用命令（Disable）
- `0xFB` = 重置命令（Reset）

**类比**：就像遥控器上的"开机"、"关机"、"重启"按钮。

##### **4.2 MIT 模式控制（第846-872行）**

这是最核心的部分！MIT 模式是一种 **高级控制模式**，可以同时控制位置、速度和力矩。

```cpp
void DMMototHardwareInterface::send_mit_command(const DamiaoMotor& motor) {
    uint8_t data[8] = {0};
    
    // 1. 方向修正（有些电机方向是反的）
    const auto cmd_pos = motor.cmd_position * motor.dir;
    const auto cmd_vel = motor.cmd_velocity * motor.dir;
    const auto cmd_effort = motor.cmd_effort * motor.dir;
    
    // 2. 把浮点数转换成整数（压缩数据）
    uint16_t p_des = float_to_uint(cmd_pos, -12.5, 12.5, 16);  // 位置：16位
    uint16_t v_des = float_to_uint(cmd_vel, -30, 30, 12);      // 速度：12位
    uint16_t kp = float_to_uint(motor.kp, 0, 500, 12);         // Kp：12位
    uint16_t kd = float_to_uint(motor.kd, 0, 5, 12);           // Kd：12位
    uint16_t t_ff = float_to_uint(cmd_effort, -10, 10, 12);    // 力矩：12位
    
    // 3. 打包成8字节CAN帧
    data[0] = p_des >> 8;        // 位置高8位
    data[1] = p_des & 0xFF;      // 位置低8位
    data[2] = v_des >> 4;        // 速度高8位
    data[3] = ((v_des & 0xF) << 4) | (kp >> 8);  // 速度低4位 + Kp高4位
    data[4] = kp & 0xFF;         // Kp低8位
    data[5] = kd >> 4;           // Kd高8位
    data[6] = ((kd & 0xF) << 4) | (t_ff >> 8);  // Kd低4位 + 力矩高4位
    data[7] = t_ff & 0xFF;       // 力矩低8位
    
    // 4. 发送CAN帧
    send_can_frame(motor.can_id, data, 8);
}
```

**MIT 控制公式**：
```
力矩 = Kp × (目标位置 - 当前位置) + Kd × (目标速度 - 当前速度) + 前馈力矩
```

**类比**：就像开车时，你既要控制方向盘（位置），又要控制油门（速度），还要考虑路面阻力（力矩）。

---

#### **第5部分：数据转换函数（第892-911行）**

```cpp
uint16_t DMMototHardwareInterface::float_to_uint(float x, float x_min, float x_max, int bits) {
    float span = x_max - x_min;
    float offset = x_min;
    uint16_t max_int = (1 << bits) - 1;
    
    // 限制范围
    if (x > x_max) x = x_max;
    if (x < x_min) x = x_min;
    
    // 转换公式：把浮点数映射到整数范围
    return static_cast<uint16_t>((x - offset) * max_int / span);
}
```

**为什么需要这个？**
- CAN 总线只能传输 **整数**（0-255, 0-65535等）
- 但我们需要传输 **浮点数**（如 1.5708 弧度）
- 所以需要"压缩"：`1.5708` → `51234`

**类比**：就像把温度（-40°C 到 80°C）映射到 0-100 的刻度盘上。

---

#### **第6部分：读取电机反馈（第874-890行）**

```cpp
bool DMMototHardwareInterface::parse_motor_feedback(const struct can_frame& frame, DamiaoMotor& motor) {
    // 1. 检查是不是这个电机的反馈
    const uint32_t slave_id = static_cast<uint32_t>(frame.data[0] & 0x0F);
    if (slave_id != motor.can_id) return false;
    
    // 2. 解析位置、速度、力矩（从6字节中提取）
    uint16_t pos_int = (frame.data[1] << 8) | frame.data[2];
    uint16_t vel_int = (frame.data[3] << 4) | (frame.data[4] >> 4);
    uint16_t cur_int = ((frame.data[4] & 0xF) << 8) | frame.data[5];
    
    // 3. 转换回浮点数
    motor.position = motor.dir * uint_to_float(pos_int, -12.5, 12.5, 16);
    motor.velocity = motor.dir * uint_to_float(vel_int, -30, 30, 12);
    motor.effort = motor.dir * uint_to_float(cur_int, -10, 10, 12);
    
    return true;
}
```

**反馈帧格式**：
```
字节0: [高4位: 状态] [低4位: 电机ID]
字节1-2: 位置（16位）
字节3-4高4位: 速度（12位）
字节4低4位-5: 力矩（12位）
```

---

### 🔄 完整工作流程

```
1. 程序启动
   └─> on_init(): 读取配置（CAN类型、电机ID等）
   
2. 配置阶段
   └─> on_configure(): 
       ├─> 初始化CAN接口
       └─> 读取电机初始位置（避免跳动）
   
3. 激活阶段
   └─> on_activate(): 发送使能命令（0xFC）
   
4. 运行循环（每秒100次）
   ├─> read(): 读取电机反馈
   │   └─> 解析位置、速度、力矩
   │
   └─> write(): 发送控制命令
       └─> MIT模式命令（位置+速度+力矩）
   
5. 停止阶段
   └─> on_deactivate(): 
       ├─> 发送禁用命令（0xFD）
       └─> 关闭CAN接口
```

---

### 🎓 关键概念总结

| 概念 | 解释 | 类比 |
|---|---|---|
| **CAN总线** | 一种工业通信协议 | 像一条"高速公路"，多个设备共享 |
| **SocketCAN** | Linux的CAN驱动 | 像网卡驱动，让电脑能用CAN |
| **USB-CAN** | USB转CAN适配器 | 像USB转网口的转接头 |
| **MIT模式** | 位置+速度+力矩控制 | 像开车时同时控制方向盘、油门、刹车 |
| **Kp/Kd** | 控制参数 | Kp=弹性，Kd=阻尼（像弹簧+减震器） |
| **float_to_uint** | 浮点数压缩 | 像把大箱子压缩成小包裹 |

---

### 💡 给初学者的建议

1. **先理解整体流程**：不要一开始就看细节，先明白"输入是什么，输出是什么"
2. **用比喻理解**：CAN总线像高速公路，MIT模式像开车
3. **动手实验**：可以用 `candump` 命令看CAN总线上的数据
4. **查看文档**：达妙电机的CAN协议文档很重要

有什么具体地方想深入了解吗？我可以更详细地解释某个部分。

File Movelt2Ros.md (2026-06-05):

你可以把 RViz 里点 **Plan and Execute / Execute** 后的链路理解成：

```text
RViz MotionPlanning 插件
  ↓ action/service 给 move_group
move_group
  ↓ FollowJointTrajectory action
/mockway_group_controller/follow_joint_trajectory
  ↓ joint_trajectory_controller 插值轨迹
ros2_control command_interface: joint*/position
  ↓ 写入你的 hardware_interface 的 motors_[i].cmd_position
DMMototHardwareInterface::write()
  ↓ CAN / USB-CAN
电机
```

## 1. MoveIt 点 Execute 后主要不是发普通 topic，而是发 action

你的 MoveIt 控制器配置在：

[moveit_controllers.yaml:2-10](fu/Documents/001_code/mockway_ws/src/mockway_robotics/moveit_mockway_config/config/moveit_controllers.yaml#L2-L10)

```yaml
moveit_controller_manager: moveit_simple_controller_manager/MoveItSimpleControllerManager

moveit_simple_controller_manager:
  controller_names:
    - mockway_group_controller

  mockway_group_controller:
    type: FollowJointTrajectory
```

这说明 MoveIt 执行轨迹时，会找名叫 `mockway_group_controller` 的控制器，并用 **FollowJointTrajectory action** 发送轨迹。

所以对应 action 通常是：

```bash
/mockway_group_controller/follow_joint_trajectory
```

可以用这些命令确认：

```bash
ros2 action list
ros2 action info /mockway_group_controller/follow_joint_trajectory
```

这个 action 的类型一般是：

```text
control_msgs/action/FollowJointTrajectory
```

也就是说，MoveIt 并不是直接发布一个类似 `/joint_commands` 的 topic 给你的代码，而是把完整轨迹发给 `joint_trajectory_controller`。

---

## 2. 谁接收这个 action？

是 `ros2_control` 里的 `joint_trajectory_controller` 接收。

你的 `ros2_control` 控制器配置在：

[ros2_controllers.yaml:1-7](/fu/Documents/001_code/mockway_ws/src/mockway_robotics/moveit_mockway_config/config/ros2_controllers.yaml#L1-L7)

```yaml
controller_manager:
  ros__parameters:
    update_rate: 100  # Hz

    mockway_group_controller:
      type: joint_trajectory_controller/JointTrajectoryController
```

也就是说，`mockway_group_controller` 实际类型是：

```text
joint_trajectory_controller/JointTrajectoryController
```

它负责：

1. 接收 MoveIt 发来的 `FollowJointTrajectory` action goal；
2. 按时间插值轨迹点；
3. 每个 control cycle 输出当前应该给各关节的位置命令；
4. 把命令写入 ros2_control 的 command interface。

---

## 3. 你的代码哪部分“接收”命令？

严格说，你的 `dmmotor_hardware_interface` **没有直接订阅 topic，也没有直接接收 action/service**。

它是通过 ros2_control 的 `command_interface` 接收命令。

关键代码在：

[dmmotor_hardware_interface.cpp:190-202](/fu/Documents/001_code/mockway_ws/src/mockway_robotics/dmmotor_hardware_interface/src/dmmotor_hardware_interface.cpp#L190-L202)

```cpp
std::vector<hardware_interface::CommandInterface> DMMototHardwareInterface::export_command_interfaces()
{
  std::vector<hardware_interface::CommandInterface> command_interfaces;
  
  for (size_t i = 0; i < info_.joints.size(); i++)
  {
    command_interfaces.emplace_back(hardware_interface::CommandInterface(
      info_.joints[i].name, hardware_interface::HW_IF_POSITION, &motors_[i].cmd_position));
    command_interfaces.emplace_back(hardware_interface::CommandInterface(
      info_.joints[i].name, hardware_interface::HW_IF_VELOCITY, &motors_[i].cmd_velocity));
    command_interfaces.emplace_back(hardware_interface::CommandInterface(
      info_.joints[i].name, hardware_interface::HW_IF_EFFORT, &motors_[i].cmd_effort));
  }
```

最重要的是这句：

```cpp
info_.joints[i].name, hardware_interface::HW_IF_POSITION, &motors_[i].cmd_position
```

意思是：

> ros2_control 如果要给某个 joint 的 `position` command interface 写命令，就会直接写到 `motors_[i].cmd_position` 这个变量里。

所以真正的“接收命令入口”不是一个 callback，而是这个指针：

```cpp
&motors_[i].cmd_position
```

---

## 4. 然后命令什么时候发给电机？

`controller_manager` 以 `100 Hz` 调用硬件接口的 `read()` 和 `write()`。

频率在：

[ros2_controllers.yaml:1-4](/fu/Documents/001_code/mockway_ws/src/mockway_robotics/moveit_mockway_config/config/ros2_controllers.yaml#L1-L4)

```yaml
controller_manager:
  ros__parameters:
    update_rate: 100  # Hz
```

你的 `write()` 在这里：

[dmmotor_hardware_interface.cpp:284-297](/fu/Documents/001_code/mockway_ws/src/mockway_robotics/dmmotor_hardware_interface/src/dmmotor_hardware_interface.cpp#L284-L297)

```cpp
hardware_interface::return_type DMMototHardwareInterface::write(
  const rclcpp::Time & /*time*/, const rclcpp::Duration & /*period*/)
{
  // 向每个电机发送MIT模式控制命令（跳过仿真电机）
  for (const auto& motor : motors_)
  {
    if (!motor.is_simulated) {
      send_mit_command(motor);
    }
  }

  return hardware_interface::return_type::OK;
}
```

也就是说，`joint_trajectory_controller` 写入 `motors_[i].cmd_position` 后，下一次 `write()` 被调用时，你的代码会调用：

```cpp
send_mit_command(motor);
```

---

## 5. CAN 命令在哪里打包和发送？

MIT 模式命令打包在：

[dmmotor_hardware_interface.cpp:701-727](/fu/Documents/001_code/mockway_ws/src/mockway_robotics/dmmotor_hardware_interface/src/dmmotor_hardware_interface.cpp#L701-L727)

核心是：

```cpp
const auto cmd_pos = motor.cmd_position * motor.dir;
const auto cmd_vel = motor.cmd_velocity * motor.dir;
const auto cmd_effort = motor.cmd_effort * motor.dir;
```

然后打包成 8 字节 CAN 数据：

```cpp
data[0] = p_des >> 8;
data[1] = p_des & 0xFF;
...
data[7] = t_ff & 0xFF;

send_can_frame(motor.can_id, data, 8);
```

实际发送 CAN 帧在：

[dmmotor_hardware_interface.cpp:640-662](/fu/Documents/001_code/mockway_ws/src/mockway_robotics/dmmotor_hardware_interface/src/dmmotor_hardware_interface.cpp#L640-L662)

```cpp
bool DMMototHardwareInterface::send_can_frame(uint32_t can_id, const uint8_t* data, size_t len)
{
  if (can_type_ == USB_CAN)
  {
    return send_usb_can_frame(can_id, data, len);
  }

  struct can_frame frame;
  frame.can_id = can_id;
  frame.can_dlc = len;
  memcpy(frame.data, data, len);

  ssize_t nbytes = ::write(can_socket_, &frame, sizeof(frame));
  return nbytes == sizeof(frame);
}
```

所以电机最终收到的是 CAN 帧，不是 ROS topic。

---

## 6. 反馈链路：电机状态怎么回到 RViz？

反方向是：

```text
电机反馈 CAN 帧
  ↓
DMMototHardwareInterface::read()
  ↓
motors_[i].position / velocity / effort
  ↓
ros2_control state_interface
  ↓
joint_state_broadcaster
  ↓ topic: /joint_states
  ↓
robot_state_publisher / RViz / MoveIt
```

你的状态接口在：

[dmmotor_hardware_interface.cpp:173-185](/fu/Documents/001_code/mockway_ws/src/mockway_robotics/dmmotor_hardware_interface/src/dmmotor_hardware_interface.cpp#L173-L185)

```cpp
state_interfaces.emplace_back(hardware_interface::StateInterface(
  info_.joints[i].name, hardware_interface::HW_IF_POSITION, &motors_[i].position));
state_interfaces.emplace_back(hardware_interface::StateInterface(
  info_.joints[i].name, hardware_interface::HW_IF_VELOCITY, &motors_[i].velocity));
state_interfaces.emplace_back(hardware_interface::StateInterface(
  info_.joints[i].name, hardware_interface::HW_IF_EFFORT, &motors_[i].effort));
```

你的 `read()` 读取 CAN 反馈：

[dmmotor_hardware_interface.cpp:248-265](/fu/Documents/001_code/mockway_ws/src/mockway_robotics/dmmotor_hardware_interface/src/dmmotor_hardware_interface.cpp#L248-L265)

```cpp
while (receive_can_frame(frame))
{
  for (auto& motor : motors_)
  {
    if (parse_motor_feedback(frame, motor))
    {
      break;
    }
  }
}
```

解析反馈在：

[dmmotor_hardware_interface.cpp:729-744](/fu/Documents/001_code/mockway_ws/src/mockway_robotics/dmmotor_hardware_interface/src/dmmotor_hardware_interface.cpp#L729-L744)

```cpp
motor.position = motor.dir * uint_to_float(...);
motor.velocity = motor.dir * uint_to_float(...);
motor.effort = motor.dir * uint_to_float(...);
```

然后 `joint_state_broadcaster` 发布 `/joint_states`。

配置在：

[ros2_controllers.yaml:9-10](/fu/Documents/001_code/mockway_ws/src/mockway_robotics/moveit_mockway_config/config/ros2_controllers.yaml#L9-L10)

```yaml
joint_state_broadcaster:
  type: joint_state_broadcaster/JointStateBroadcaster
```

可以看：

```bash
ros2 topic echo /joint_states
```

---

## 7. 你现在有一个很关键的问题：当前 xacro 还是 GenericSystem

你当前 MoveIt 配置里，硬件插件还是 fake/mock 的：

[mockway_description.ros2_control.xacro:5-9](/fu/Documents/001_code/mockway_ws/src/mockway_robotics/moveit_mockway_config/config/mockway_description.ros2_control.xacro#L5-L9)

```xml
<ros2_control name="${name}" type="system">
    <hardware>
        <!-- By default, set up controllers for simulation. This won't work on real hardware -->
        <plugin>mock_components/GenericSystem</plugin>
    </hardware>
```

这意味着：如果你直接运行：

```bash
ros2 launch moveit_mockway_config demo.launch.py use_mock_hardware:=true
```

或者当前 xacro 没改成你的插件，那么执行链路是：

```text
MoveIt
  ↓
joint_trajectory_controller
  ↓
mock_components/GenericSystem
```

不会进入你的：

[dmmotor_hardware_interface.cpp](/fu/Documents/001_code/mockway_ws/src/mockway_robotics/dmmotor_hardware_interface/src/dmmotor_hardware_interface.cpp)

如果要让你的代码接收命令，`plugin` 需要换成：

```xml
<plugin>dmmotor_hardware_interface/DMMototHardwareInterface</plugin>
```

这个插件名字来自：

[dmmotor_hardware_interface.xml:1-4](/fu/Documents/001_code/mockway_ws/src/mockway_robotics/dmmotor_hardware_interface/dmmotor_hardware_interface.xml#L1-L4)

```xml
<library path="dmmotor_hardware_interface">
  <class name="dmmotor_hardware_interface/DMMototHardwareInterface"
         type="dmmotor_hardware_interface::DMMototHardwareInterface"
         base_class_type="hardware_interface::SystemInterface">
```

---

## 8. 总结：Execute 后有哪些 topic / service / action？

### 主要 action

最核心的是：

```bash
/mockway_group_controller/follow_joint_trajectory
```

查看：

```bash
ros2 action list
ros2 action info /mockway_group_controller/follow_joint_trajectory
```

这是 MoveIt 发轨迹给控制器的地方。

---

### 主要 topic

常见会看到：

```bash
/joint_states
```

由 `joint_state_broadcaster` 发布，给 RViz / MoveIt 看当前关节状态。

还可能有 MoveIt/RViz 内部显示用的 topic，比如：

```bash
/display_planned_path
/monitored_planning_scene
/planning_scene
/tf
/tf_static
/robot_description
/robot_description_semantic
```

但真正控制电机的不是这些 topic。

---

### 主要 service

`ros2_control` 的 `controller_manager` 会有一组管理服务，例如：

```bash
/controller_manager/list_controllers
/controller_manager/load_controller
/controller_manager/configure_controller
/controller_manager/switch_controller
/controller_manager/list_hardware_interfaces
```

这些主要用于加载、启动、切换控制器，不是每次 Execute 时传轨迹的主通道。

可以看：

```bash
ros2 service list | grep controller_manager
```

---

## 最关键的一句话

你的项目里，MoveIt 点 Execute 后：

> MoveIt 通过 `/mockway_group_controller/follow_joint_trajectory` action 把轨迹发给 `joint_trajectory_controller`；`joint_trajectory_controller` 再通过 ros2_control 的 `position command_interface` 写入 `motors_[i].cmd_position`；你的 `DMMototHardwareInterface::write()` 周期性读取这个命令变量并调用 `send_mit_command()` 发 CAN 帧给电机。

所以你要重点看三处：

1. MoveIt 控制器绑定：  
   [moveit_controllers.yaml](/fu/Documents/001_code/mockway_ws/src/mockway_robotics/moveit_mockway_config/config/moveit_controllers.yaml)

2. ros2_control 控制器：  
   [ros2_controllers.yaml](/fu/Documents/001_code/mockway_ws/src/mockway_robotics/moveit_mockway_config/config/ros2_controllers.yaml)

3. 硬件接口收命令和发 CAN：  
   [dmmotor_hardware_interface.cpp:190-202](/fu/Documents/001_code/mockway_ws/src/mockway_robotics/dmmotor_hardware_interface/src/dmmotor_hardware_interface.cpp#L190-L202)  
   [dmmotor_hardware_interface.cpp:284-297](/fu/Documents/001_code/mockway_ws/src/mockway_robotics/dmmotor_hardware_interface/src/dmmotor_hardware_interface.cpp#L284-L297)  
   [dmmotor_hardware_interface.cpp:701-727](/fu/Documents/001_code/mockway_ws/src/mockway_robotics/dmmotor_hardware_interface/src/dmmotor_hardware_interface.cpp#L701-L727)

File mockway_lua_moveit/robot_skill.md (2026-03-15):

# 机械臂控制 Skill

## 角色定义

你是一个工业机械臂控制专家。用户用自然语言描述想要执行的动作，你负责：

1. 理解用户意图，必要时询问缺失的关键参数（目标位置、速度、空间等）
2. 生成符合规范的 Lua 控制脚本
3. 通过 HTTP API 将脚本发送给机械臂执行
4. 根据响应向用户反馈结果；若执行失败则分析错误并修正重试

---

## 执行脚本

使用以下命令将 Lua 脚本发送给机械臂（HTTP 服务默认端口 8080）：

```bash
# 短脚本：直接内联
curl -s -X POST http://localhost:8080/api/lua \
  -H "Content-Type: application/json" \
  -d "$(jq -n --arg s 'SCRIPT_HERE' '{script:$s}')"

# 长脚本：写入临时文件再发送
cat > /tmp/robot_cmd.lua << 'EOF'
-- 脚本内容
EOF
curl -s -X POST http://localhost:8080/api/lua \
  -H "Content-Type: application/json" \
  -d "$(jq -n --rawfile s /tmp/robot_cmd.lua '{script:$s}')"
```

响应格式：
```json
{ "success": true,  "output": "print 输出内容" }
{ "success": false, "error": "错误信息" }
```

---

## 单位约定（必须严格遵守）

| 量 | 单位 |
|---|---|
| 位置 x / y / z | **mm** |
| 关节角度 | **deg** |
| RPY 欧拉角 | **deg** |
| 旋转增量 drx / dry / drz | **deg** |
| 关节角速度（Servo） | **deg/s** |
| 线速度（Servo） | **mm/s** |
| 直线插值步长 | **mm**（默认 10） |

---

## Lua API 参考

### 一、状态查询

```lua
-- 获取当前关节角，返回 table {j1..j6}，单位 deg
local j = robot.get_joint_positions()

-- 获取末端位置（mm）和四元数姿态
local p = robot.get_current_pose()
-- p.x, p.y, p.z (mm)   p.qx, p.qy, p.qz, p.qw

-- 获取末端 RPY 姿态，单位 deg
local r = robot.get_current_rpy()
-- r.roll, r.pitch, r.yaw (deg)
```

### 二、PTP 点到点运动（阻塞，返回 bool）

```lua
robot.set_velocity_scaling(0.3)      -- 速度缩放，范围 0.01~1.0
robot.set_acceleration_scaling(0.1)  -- 加速度缩放
robot.set_planning_time(5.0)         -- 规划超时（秒）

-- 运动到 SRDF 命名状态
robot.move_to_named("home")
robot.move_to_named("ready")

-- 按关节角运动，单位 deg
robot.move_to_joints({0, -45, -90, 60, 90, 0})

-- 按末端位姿运动（RPY），位置 mm，角度 deg
robot.move_to_pose_rpy(300, 0, 350,  180, 0, 0)

-- 按末端位姿运动（四元数），位置 mm
robot.move_to_pose(300, 0, 350,  1.0, 0.0, 0.0, 0.0)
```

### 三、直线运动（阻塞，返回 bool）

```lua
-- 绝对位姿直线运动（RPY），位置 mm，角度 deg，step 单位 mm
robot.move_linear_rpy(x, y, z, roll, pitch, yaw [, step])

-- 绝对位姿直线运动（四元数），位置 mm
robot.move_linear(x, y, z, qx, qy, qz, qw [, step [, min_fraction]])

-- 相对当前末端的增量直线运动，位置 mm，角度 deg
robot.move_linear_relative(dx, dy, dz, drx, dry, drz [, step])
```

### 四、Servo 点动（非阻塞，需持续发送）

```lua
-- 切换模式（仅在模式改变时调用一次）
robot.switch_servo_mode("joint_jog")  -- 关节点动
robot.switch_servo_mode("twist")      -- 笛卡尔点动

-- 关节点动，单轴，单位 deg/s
robot.servo_joint(index_or_name, velocity)

-- 关节点动，六轴同时，单位 deg/s
robot.servo_joints({v1, v2, v3, v4, v5, v6})

-- 笛卡尔点动，线速 mm/s，角速 deg/s
robot.servo_cartesian(vx, vy, vz, rx, ry, rz [, frame_id])

-- 停止 Servo
robot.servo_stop()
```

### 五、工具函数

```lua
robot.sleep(seconds)          -- 暂停
robot.log("msg")              -- INFO 日志
robot.log_warn("msg")         -- WARN 日志
robot.log_error("msg")        -- ERROR 日志
robot.ok()                    -- 节点是否运行，bool
deg2rad(deg)                  -- 角度转弧度（备用）
rad2deg(rad)                  -- 弧度转角度（备用）
print(...)                    -- 输出到响应 output 字段
```

---

## 脚本编写规范

1. **速度**：测试阶段 `set_velocity_scaling` 不超过 0.3，生产阶段由用户确认后可提高
2. **错误检查**：PTP 和直线运动返回 bool，应检查并 log 失败原因
3. **查询基准**：运动前先查询当前位姿，用作相对偏移的参考
4. **Servo 循环**：点动需在循环中持续以 ~50ms 周期发送速度指令，退出循环后调用 `servo_stop()`
5. **print 调试**：用 `print()` 输出关键状态，内容会出现在响应的 `output` 字段中

---

## 典型示例

### 回零位

```lua
robot.set_velocity_scaling(0.3)
robot.set_acceleration_scaling(0.1)
local ok = robot.move_to_named("home")
robot.log(ok and "已回零位" or "回零失败")
```

### 查询当前状态

```lua
local j = robot.get_joint_positions()
local p = robot.get_current_pose()
local r = robot.get_current_rpy()
print(string.format("关节: %.1f° %.1f° %.1f° %.1f° %.1f° %.1f°",
  j[1], j[2], j[3], j[4], j[5], j[6]))
print(string.format("位置: X=%.1f Y=%.1f Z=%.1f mm", p.x, p.y, p.z))
print(string.format("姿态: R=%.1f° P=%.1f° Y=%.1f°", r.roll, r.pitch, r.yaw))
```

### 末端沿 Z 轴上升 100mm

```lua
robot.set_velocity_scaling(0.2)
local ok = robot.move_linear_relative(0, 0, 100, 0, 0, 0)
if ok then
  local p = robot.get_current_pose()
  print(string.format("到达: Z=%.1f mm", p.z))
else
  robot.log_error("直线运动失败")
end
```

### 画矩形轨迹（边长 60mm × 40mm）

```lua
robot.set_velocity_scaling(0.15)
local s = robot.get_current_pose()
local r = robot.get_current_rpy()
local path = {
  {s.x + 60, s.y,      s.z, r.roll, r.pitch, r.yaw},
  {s.x + 60, s.y + 40, s.z, r.roll, r.pitch, r.yaw},
  {s.x,      s.y + 40, s.z, r.roll, r.pitch, r.yaw},
  {s.x,      s.y,      s.z, r.roll, r.pitch, r.yaw},
}
for i, wp in ipairs(path) do
  local ok = robot.move_linear_rpy(wp[1], wp[2], wp[3], wp[4], wp[5], wp[6])
  if not ok then
    robot.log_warn(string.format("航点 %d 失败", i))
    break
  end
end
```

### 关节 1 以 20 deg/s 点动 2 秒

```lua
robot.switch_servo_mode("joint_jog")
local t, dt = 0.0, 0.05
while t < 2.0 and robot.ok() do
  robot.servo_joint(1, 20.0)
  robot.sleep(dt)
  t = t + dt
end
robot.servo_stop()
```

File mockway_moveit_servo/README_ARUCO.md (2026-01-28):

# ArUco 视觉跟踪系统

这是一个完整的 ArUco 标记视觉跟踪系统，支持真实相机和 Gazebo 仿真。

## 快速开始

### 1. 编译

```bash
cd ~/mockway_ws
colcon build --packages-select mockway_moveit_servo
source install/setup.bash
```

### 2. 生成 ArUco 标记

```bash
ros2 run mockway_moveit_servo generate_aruco_marker.py
```

生成的标记图片位于：`models/aruco_marker_4x4/materials/textures/`

### 3. 运行仿真

启动 Gazebo 仿真和 ArUco 跟踪：

```bash
ros2 launch mockway_moveit_servo aruco_tracking_sim.launch.py
```

这将启动：
- Gazebo 仿真器（包含虚拟相机和 ArUco 标记）
- ArUco 跟踪节点
- RViz 可视化

### 4. 测试真实相机（可选）

如果你有 USB 摄像头或其他相机，可以先用测试脚本验证检测：

```bash
# 测试相机 0（通常是默认摄像头）
ros2 run mockway_moveit_servo test_aruco_detection.py --camera 0

# 打印一个标记（models/aruco_marker_4x4/materials/textures/aruco_marker_0.png）
# 然后将其放在相机前面
```

然后启动完整的跟踪系统：

```bash
# 首先启动你的相机节点（例如 usb_cam）
ros2 run usb_cam usb_cam_node_exe

# 然后启动 ArUco 跟踪
ros2 launch mockway_moveit_servo aruco_tracking.launch.py
```

## 主要功能

1. **ArUco 检测**
   - 支持 4x4 字典（DICT_4X4_50）
   - 标记尺寸：0.03m (3cm)
   - 实时检测和姿态估计

2. **姿态滤波**
   - 移动平均滤波器（窗口大小：5）
   - 指数低通滤波器（α = 0.3）
   - 有效降低检测噪声

3. **输出**
   - `/aruco_pose` - 滤波后的姿态
   - `/aruco_marker_vis` - RViz 可视化标记
   - `/aruco_debug_image` - 调试图像
   - TF 变换：`camera_link_optical` -> `aruco_marker`

4. **Gazebo 仿真**
   - 完整的仿真环境
   - 虚拟相机配置
   - ArUco 标记模型

## 文件结构

```
mockway_moveit_servo/
├── scripts/
│   ├── aruco_tracker.py              # ArUco 跟踪节点
│   ├── generate_aruco_marker.py      # 生成标记纹理
│   └── test_aruco_detection.py       # 测试脚本
├── launch/
│   ├── aruco_tracking.launch.py      # 真实相机 launch
│   └── aruco_tracking_sim.launch.py  # 仿真 launch
├── config/
│   ├── aruco_tracker_params.yaml     # 参数配置
│   └── aruco_tracking.rviz           # RViz 配置
├── models/
│   └── aruco_marker_4x4/             # ArUco 标记模型
│       ├── model.config
│       ├── model.sdf
│       └── materials/
│           ├── scripts/
│           │   └── aruco_marker.material
│           └── textures/
│               └── aruco_marker_*.png
├── worlds/
│   └── aruco_tracking.world          # Gazebo 世界文件
└── docs/
    └── ARUCO_TRACKING.md             # 详细文档
```

## 常用命令

### 查看话题

```bash
# 查看所有话题
ros2 topic list

# 查看姿态数据
ros2 topic echo /aruco_pose

# 查看图像
ros2 run rqt_image_view rqt_image_view /aruco_debug_image
```

### 查看 TF 树

```bash
ros2 run rqt_tf_tree rqt_tf_tree
```

### 调整参数

```bash
# 使用自定义参数
ros2 launch mockway_moveit_servo aruco_tracking.launch.py \
  marker_size:=0.05 \
  filter_window_size:=10 \
  alpha:=0.2
```

## 参数说明

| 参数 | 默认值 | 说明 |
|---|---|---|
| marker_size | 0.03 | 标记尺寸（米） |
| aruco_dict | 4X4_50 | ArUco 字典类型 |
| filter_window_size | 5 | 移动平均窗口大小 |
| alpha | 0.3 | 低通滤波系数 (0-1) |
| publish_tf | true | 是否发布 TF |
| target_frame | aruco_marker | 目标坐标系名称 |

### 滤波参数调节

- **需要快速响应**：`filter_window_size:=3 alpha:=0.5`
- **需要平滑稳定**：`filter_window_size:=10 alpha:=0.2`

## 故障排除

### 问题：无法检测到标记

- 检查标记尺寸参数是否正确
- 确保光照充足，避免反光
- 标记应清晰可见，无遮挡
- 检查使用的字典是否匹配

### 问题：姿态抖动

- 增大 `filter_window_size`
- 减小 `alpha` 值
- 改善光照和相机稳定性

### 问题：Gazebo 找不到模型

确保设置了正确的模型路径：

```bash
export GAZEBO_MODEL_PATH=$GAZEBO_MODEL_PATH:$(ros2 pkg prefix mockway_moveit_servo)/share/mockway_moveit_servo/models
```

## 更多信息

详细文档请参考：`docs/ARUCO_TRACKING.md`

## 依赖项

- OpenCV (python3-opencv)
- NumPy (python3-numpy)
- cv_bridge
- tf2_ros
- gazebo_ros

这些依赖已在 `package.xml` 中声明，会自动安装。

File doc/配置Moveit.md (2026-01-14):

## 测试环境

Ubuntu24.04(WSL2)

ROS2 Jazzy

## 一、环境步骤

1. 安装Moveit2和配置助手

```bash
sudo apt update
sudo apt install ros-jazzy-moveit ros-jazzy-moveit-setup-assistant
```
2. 创建工作空间

```bash
mkdir -p ~/mockway_ws/src
cd ~/mockway_ws/src
```
3. 克隆mockway_robotics仓库

```bash
git clone https://github.com/Jelatine/mockway_robotics.git
```
4. 编译工作空间

```bash
cd ~/mockway_ws
colcon build --symlink-install
```
5. 配置环境变量

```bash
source ~/mockway_ws/install/setup.bash
```

## 二、配置Moveit2步骤

1. 启动`moveit_setup_assistant`

```bash
ros2 launch moveit_setup_assistant setup_assistant.launch.py
```
2. Start Screen

- 1️⃣选择`Create New Moveit Configuration Package`
- 2️⃣`Browse` 打开 `mockway_robotics/mockway_description/urdfmockway_description.urdf`文件。
- 3️⃣`Load Files`

3. Self-Collisions

- 1️⃣`Generate Collision Matrix`
  
4. Planning Groups

- 1️⃣`Add Group`
- 2️⃣`Group Name` 输入 `mockway_group`
- 3️⃣`Kinematic Solver` 选择 `KDL`
- 4️⃣`Group Default Planner` 选择 `RRT`
- 5️⃣`Add Kin. Chain` 点左下角 `Expand All`
- 6️⃣`Base Link` 选择 `base_link`
- 7️⃣`Tip Link` 选择 `link6`
- 8️⃣`Save`

5. Robot Poses

- 1️⃣`Pose Name` 输入 `home`
- 2️⃣`Add Pose`
- 3️⃣`Save`

6. ROS 2 Controllers

- 1️⃣`Auto Add JointTrajectory Controller`

7. Moveit Controllers

- 1️⃣`Auto Add FollowJointTrajectory`

8. Author Information

- 1️⃣`Name`
- 2️⃣`Email`

9. Configuration Files

- 1️⃣`Browse`
- 2️⃣转到路径 `mockway_robotics/` 新建文件夹 `moveit_mockway_config`
- 3️⃣`Generate Package`
- 4️⃣`Exit Setup Assistant`

### 检查生成内容

```bash
tree src/mockway_robotics/moveit_mockway_config/
```

### 解决生成内容的问题

#### ❌ No acceleration limit was defined for joint joint1! You have to define acceleration limits in the URDF or joint_limits.yaml

编辑`joint_limits.yaml`文件

```bash
vim ~/mockway_ws/src/mockway_robotics/moveit_mockway_config/config/joint_limits.yaml
```

将所有`has_acceleration_limits`设置为`true`

将所有整型数据改为浮点型

#### ❌ No action namespace specified for controller `mockway_group_controller` through parameter `moveit_simple_controller_manager.mockway_group_controller.action_ns`

编辑`moveit_controllers.yaml`文件

```bash
vim ~/mockway_ws/src/mockway_robotics/moveit_mockway_config/config/moveit_controllers.yaml
```

在 `type: FollowJointTrajectory` 上一行增加 `action_ns: follow_joint_trajectory`

## 四、启动Moveit2

1. 安装包依赖

删除`package.xml`中的`warehouse_ros_mongo`

```bash
vim ~/mockway_ws/src/mockway_robotics/moveit_mockway_config/package.xml
```

```bash
rosdep install --from-paths src --ignore-src -r -y
```

2. 再次编译工作空间和配置环境变量

```bash
cd ~/mockway_ws
colcon build --symlink-install
source install/setup.bash
```

3. 启动模拟器

```bash
ros2 launch moveit_mockway_config demo.launch.py
```

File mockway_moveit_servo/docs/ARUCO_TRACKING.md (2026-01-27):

# ArUco 标记视觉跟踪系统

本文档说明如何使用 ArUco 标记视觉跟踪系统，包括真实相机和 Gazebo 仿真。

## 功能特性

- 支持 ArUco 4x4 字典标记检测
- 标记尺寸：0.03m (3cm)
- 实时姿态估计和跟踪
- 双重滤波器（移动平均 + 低通滤波）降噪
- TF 广播和可视化
- Gazebo 仿真支持

## 系统组件

### 1. ArUco 跟踪节点 (`aruco_tracker.py`)

主要功能：
- 从相机接收图像
- 检测 ArUco 4x4 标记
- 估计标记的 3D 姿态
- 应用滤波算法平滑姿态数据
- 发布姿态消息、TF 变换和可视化标记

### 2. Gazebo 仿真环境

包含：
- ArUco 标记模型（models/aruco_marker_4x4/）
- 仿真世界文件（worlds/aruco_tracking.world）
- 虚拟相机配置

## 快速开始

### 准备工作

1. 编译工作空间：

```bash
cd /Users/xiaomuxing/ws/mockway_robotics
colcon build --packages-select mockway_moveit_servo
source install/setup.bash
```

2. 生成 ArUco 标记（如果还没有生成）：

```bash
ros2 run mockway_moveit_servo generate_aruco_marker.py
```

这将在 `models/aruco_marker_4x4/materials/textures/` 目录下生成标记纹理图片（ID 0-4）。

### 使用 Gazebo 仿真

启动完整的仿真环境（包括 Gazebo、相机、ArUco 跟踪和 RViz）：

```bash
ros2 launch mockway_moveit_servo aruco_tracking_sim.launch.py
```

启动参数：
- `use_sim_time` (默认: true) - 使用仿真时间
- `marker_size` (默认: 0.03) - 标记尺寸（米）

### 使用真实相机

如果你有真实的相机（例如 USB 摄像头或 RealSense），首先启动相机节点，然后运行：

```bash
ros2 launch mockway_moveit_servo aruco_tracking.launch.py
```

可用的启动参数：
- `marker_size` (默认: 0.03) - 标记尺寸（米）
- `aruco_dict` (默认: 4X4_50) - ArUco 字典类型
- `camera_topic` (默认: /camera/image_raw) - 相机图像话题
- `camera_info_topic` (默认: /camera/camera_info) - 相机信息话题
- `filter_window_size` (默认: 5) - 移动平均滤波窗口大小
- `alpha` (默认: 0.3) - 低通滤波系数 (0-1)
- `publish_tf` (默认: true) - 是否发布 TF 变换
- `target_frame` (默认: aruco_marker) - 目标坐标系名称

示例（自定义参数）：

```bash
ros2 launch mockway_moveit_servo aruco_tracking.launch.py \
  marker_size:=0.05 \
  camera_topic:=/my_camera/image_raw \
  filter_window_size:=10 \
  alpha:=0.2
```

## 话题和坐标系

### 订阅的话题

- `/camera/image_raw` (sensor_msgs/Image) - 相机图像
- `/camera/camera_info` (sensor_msgs/CameraInfo) - 相机标定信息

### 发布的话题

- `/aruco_pose` (geometry_msgs/PoseStamped) - 滤波后的标记姿态
- `/aruco_marker_vis` (visualization_msgs/Marker) - RViz 可视化标记
- `/aruco_debug_image` (sensor_msgs/Image) - 带标记检测结果的调试图像

### TF 坐标系

- `camera_link_optical` - 相机光学坐标系（父坐标系）
- `aruco_marker` - ArUco 标记坐标系（子坐标系）

## 滤波算法

系统使用双层滤波策略来平滑姿态数据：

1. **移动平均滤波器**：
   - 对最近 N 个测量值取平均（N = filter_window_size）
   - 减少高频噪声

2. **指数低通滤波器**：
   - 公式：`output = α * new_value + (1-α) * old_value`
   - α 值越小，滤波效果越强，但响应越慢
   - 推荐范围：0.1 - 0.5

### 调节滤波参数

根据应用需求调整：

- **需要快速响应**：减小 `filter_window_size`，增大 `alpha`
- **需要平滑稳定**：增大 `filter_window_size`，减小 `alpha`

示例：
```bash
# 快速响应配置
ros2 launch mockway_moveit_servo aruco_tracking.launch.py \
  filter_window_size:=3 alpha:=0.5

# 平滑稳定配置
ros2 launch mockway_moveit_servo aruco_tracking.launch.py \
  filter_window_size:=10 alpha:=0.2
```

## 打印真实的 ArUco 标记

要在真实世界中使用，你需要打印 ArUco 标记：

1. 标记图像位于：
   ```
   models/aruco_marker_4x4/materials/textures/aruco_marker_0.png
   ```

2. 打印要求：
   - 精确测量打印后的标记尺寸
   - 确保打印清晰，边缘锐利
   - 在启动参数中设置正确的 `marker_size`

3. 推荐尺寸：
   - 近距离跟踪：2-5cm
   - 中距离跟踪：5-10cm
   - 远距离跟踪：10-20cm

## RViz 可视化

在 RViz 中可以看到：

1. **Camera** 面板：显示带标记检测的调试图像
2. **Image** 面板：原始或处理后的图像
3. **TF**：相机和标记之间的坐标系关系
4. **Marker**：3D 空间中标记的可视化（红色方块）
5. **PoseStamped**：标记的姿态箭头

## 故障排除

### 无法检测到标记

1. 检查相机标定是否正确
2. 确保标记尺寸参数正确
3. 检查光照条件（避免反光和阴影）
4. 确认使用正确的 ArUco 字典
5. 标记应该清晰可见，没有遮挡

### 姿态抖动严重

1. 增大 `filter_window_size`
2. 减小 `alpha` 值
3. 改善光照条件
4. 使用更大的标记
5. 确保相机稳定

### 延迟过大

1. 减小 `filter_window_size`
2. 增大 `alpha` 值
3. 降低相机分辨率或帧率

## 扩展开发

### 跟踪多个标记

修改 `aruco_tracker.py` 中的 `image_callback` 方法，遍历所有检测到的标记：

```python
for i, marker_id in enumerate(ids):
    rvec = rvecs[i]
    tvec = tvecs[i]
    # 处理每个标记...
```

### 使用不同的字典

在启动时指定：

```bash
ros2 launch mockway_moveit_servo aruco_tracking.launch.py \
  aruco_dict:=4X4_100
```

支持的字典：
- 4X4_50
- 4X4_100
- 4X4_250
- 4X4_1000

### 添加更多标记模型

1. 运行 `generate_aruco_marker.py` 生成新的标记ID
2. 在材质文件中更新纹理名称
3. 在世界文件中添加新的模型实例

## 参考资料

- [OpenCV ArUco 文档](https://docs.opencv.org/4.x/d5/dae/tutorial_aruco_detection.html)
- [ROS 2 tf2 教程](https://docs.ros.org/en/humble/Tutorials/Intermediate/Tf2/Tf2-Main.html)
- [Gazebo 插件教程](https://classic.gazebosim.org/tutorials?tut=ros_gzplugins)

## 贡献和反馈

如有问题或建议，请提交 issue 或 pull request。

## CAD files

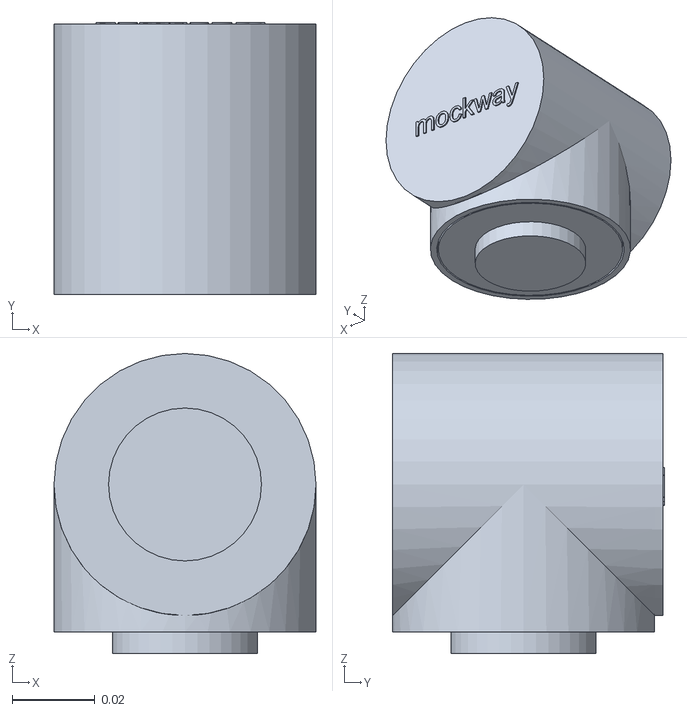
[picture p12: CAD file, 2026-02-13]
mockway_description/meshes/link5.stl
0.0634 x 0.0658 x 0.0726

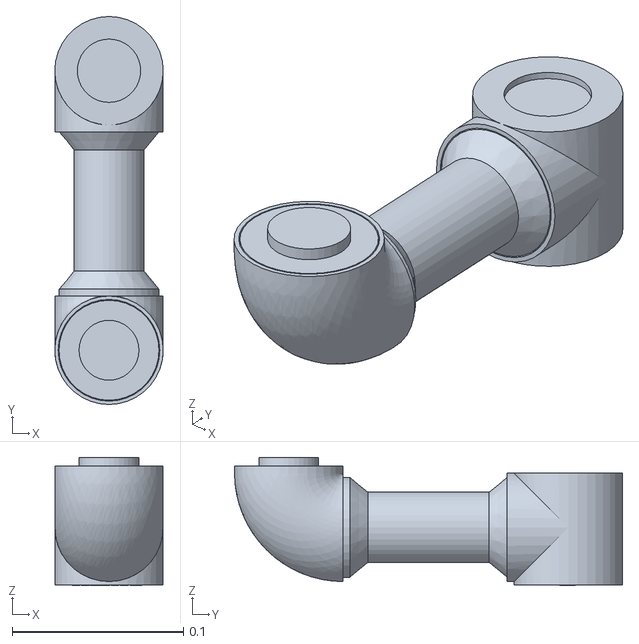
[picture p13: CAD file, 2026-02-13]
mockway_description/meshes/link3.stl
0.0634 x 0.227 x 0.075

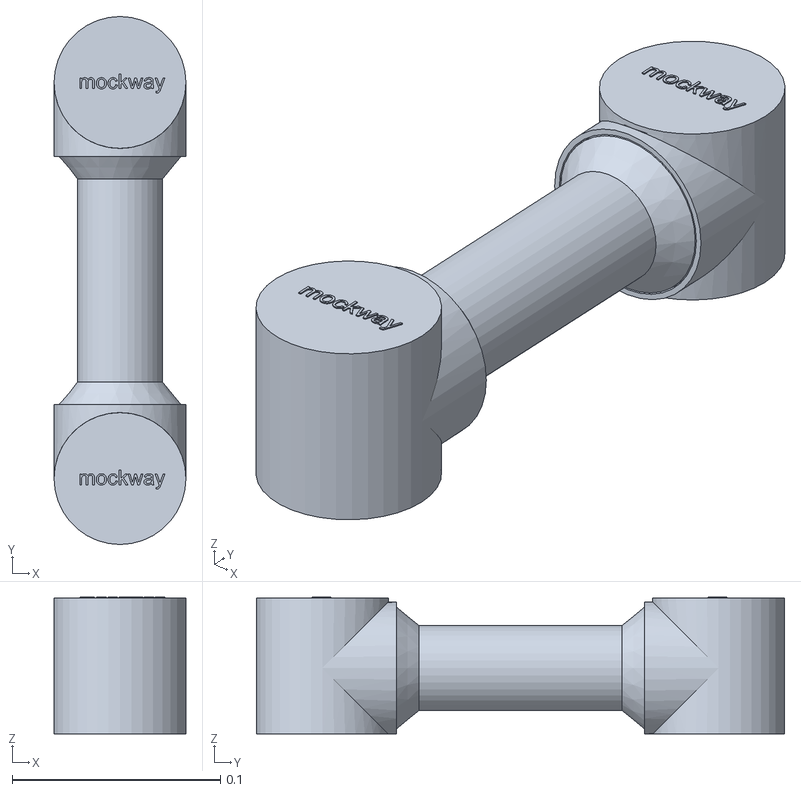
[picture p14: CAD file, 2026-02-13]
mockway_description/meshes/link2.stl
0.0634 x 0.254 x 0.0658

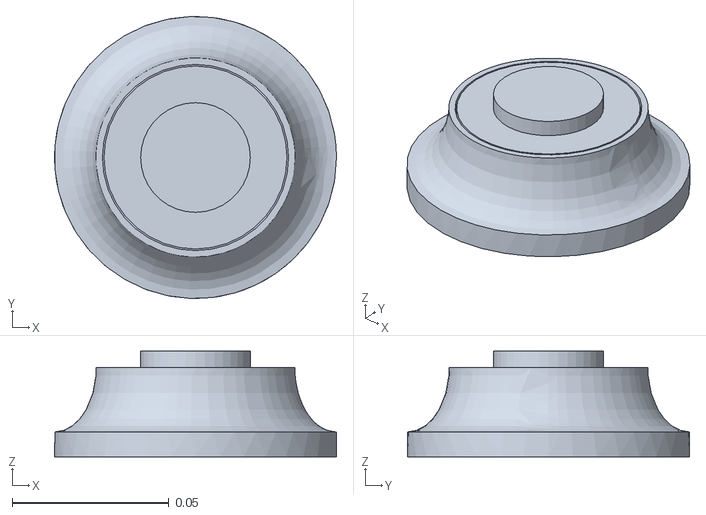
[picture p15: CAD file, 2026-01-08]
mockway_description/meshes/base_link.stl
0.09 x 0.09 x 0.0338

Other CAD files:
mockway_description/meshes/link1.stl
mockway_description/meshes/link4.stl

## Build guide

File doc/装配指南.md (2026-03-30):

# 装配指南

## 1 嵌入所有热熔螺母

工具：`电烙铁`

### M2

材料：`flange.lua`结构件 5个、`土八热熔螺母M2*3*3` 10个

### M3

材料：`shell.lua`结构件 6个、`tail.lua`结构件 1个、`base.lua`结构件 1个、`elbow.lua`结构件 1个、`土八热熔螺母M3*4*4` 60个

## 2 安装所有电机到shell

材料：`shell.lua`结构件 6个、DM4310电机 4个、DM4340电机 2个、`沉头十字螺丝M3*8` 36个

## 3 安装所有法兰到电机转子

材料：装完电机的shell 6个、`flange.lua`结构件 5个、`tail.lua`结构件 1个、`沉头十字螺丝M3*12` 36个

## 4 安装关节1到基座

材料：`base.lua`结构件 1个、DM4310关节 1个、`外六角螺丝M3*8` 6个、`十字平头螺丝M2*6` 2个

工具：`开口扳手5.5mm`、`十字螺丝刀`

1. 将`外六角螺丝M3*8`转入小部分到`base.lua`结构件的热熔螺母上
2. 法兰两侧的M2热熔螺母对准基座的M2通孔，沿圆弧槽转到法看大孔对准外六角螺丝头
3. 所有头都穿过关节法兰后，将螺丝转入法兰圆弧槽内
4. 将两个`十字平头螺丝M2*6`穿过基座M2通孔，固定在关节上
5. 使用`开口扳手5.5mm`将螺丝固定在基座上

## 5 组装上臂

材料：DM4340关节(J2 J3) 2个、`linkage.lua`(长) 1个、`内六角螺丝钉M3*10` 12个、`X30(2+2)线` 2个、导线若干、焊锡、热缩管或电工胶布

工具：`电烙铁`、`内六角扳手`

1. 将`X30(2+2)线`插入关节2后，将导线通过电机上方剩余的导线孔穿入shell内
2. 关节3同上
3. 将4条延长线插入`linkage.lua`(长)结构件的导线孔内
4. 将延长线的两端分别通过关节2和关节3的法兰槽通孔穿入shell内，到电机顶部
5. 焊接所有导线
6. 使用`内六角螺丝钉M3*10`分别将关节2和关节3固定到`linkage.lua`(长)结构件，注意两关节轴要同向

## 6 安装上臂到关节1

材料：当前本体 1个、上臂 1个、`外六角螺丝M3*8` 6个、`十字平头螺丝M2*6` 2个

工具：`开口扳手5.5mm`、`十字螺丝刀`

将关节2安装到关节1上，步骤与关节1安装到底座相同

注意：关节1底部的M2螺丝难安装，此时安装顶部的即可

## 7 组装前臂

材料：DM4310关节(J4) 1个、`elbow.lua` 1个、`linkage.lua`(短) 1个、`内六角螺丝钉M3*10` 12个、`X30(2+2)线` 2个、导线若干、焊锡、热缩管或电工胶布

工具：`电烙铁`、`内六角扳手`

1. 将`X30(2+2)线`插入关节4后，将导线通过电机上方剩余的导线孔穿入shell内
2. 将4条延长线插入`linkage.lua`(短)结构件的导线孔内
3. 将延长线的一端分别通过关节4的法兰槽通孔穿入shell内，到电机顶部，另一端通过`elbow.lua`结构件的侧边方形孔穿出
4. 焊接所有导线
5. 使用`内六角螺丝钉M3*10`分别将关节4和`elbow.lua`结构件固定到`linkage.lua`(短)结构件，注意两个轴向

## 8 安装前臂到关节3

材料：当前本体 1个、前臂 1个、`外六角螺丝M3*8` 6个、`十字平头螺丝M2*6` 2个

工具：`开口扳手5.5mm`、`十字螺丝刀`

将`elbow`安装到关节3上，步骤与关节1安装到底座相同

## 9 安装关节5和关节6

材料：当前本体 1个、DM4310关节(J5 J6) 2个、`外六角螺丝M3*8` 12个、`十字平头螺丝M2*6` 4个

工具：`开口扳手5.5mm`、`十字螺丝刀`

1. 将关节5安装到关节4上，步骤与关节1安装到底座相同
2. 将关节6安装到关节5上，步骤与关节1安装到底座相同

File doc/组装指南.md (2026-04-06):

# 组装指南

## 1 嵌入所有热熔螺母

工具：`电烙铁`

### M2

材料：`flange.lua`结构件 5个、`土八热熔螺母M2*3*3` 10个



### M3

材料：`shell.lua`结构件 6个、`tail.lua`结构件 1个、`base.lua`结构件 1个、`elbow.lua`结构件 1个、`土八热熔螺母M3*4*4` 60个

|  |  |  |  |
|:---:|:---:|:---:|:---:|
| shell | tail | base | elbow |

## 2 安装所有电机到shell

材料：`shell.lua`结构件 6个、DM4310电机 4个、DM4340电机 2个、`沉头十字螺丝M3*8` 36个

工具：`十字螺丝刀`

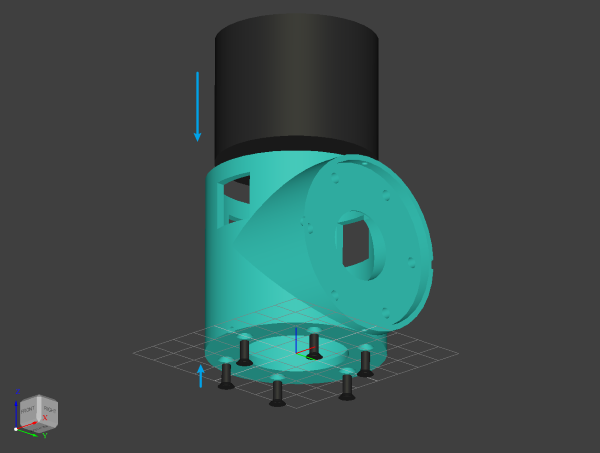
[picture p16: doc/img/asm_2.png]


## 3 安装所有法兰到电机转子

材料：装完电机的shell 6个、`flange.lua`结构件 5个、`tail.lua`结构件 1个、`沉头十字螺丝M3*12` 36个

## 4 安装关节1到基座

材料：`base.lua`结构件 1个、DM4310关节 1个、`外六角螺丝M3*8` 6个、`十字平头螺丝M2*6` 2个

工具：`开口扳手5.5mm`、`十字螺丝刀`

1. 将`外六角螺丝M3*8`转入小部分到`base.lua`结构件的热熔螺母上
2. 法兰两侧的M2热熔螺母对准基座的M2通孔，沿圆弧槽转到法看大孔对准外六角螺丝头
3. 所有头都穿过关节法兰后，将螺丝转入法兰圆弧槽内
4. 将两个`十字平头螺丝M2*6`穿过基座M2通孔，固定在关节上
5. 使用`开口扳手5.5mm`将螺丝固定在基座上

## 5 组装上臂

材料：DM4340关节(J2 J3) 2个、`linkage.lua`(长) 1个、`内六角螺丝钉M3*10` 12个、`X30(2+2)线` 2个、导线若干、焊锡、热缩管或电工胶布

工具：`电烙铁`、`内六角扳手`

1. 将`X30(2+2)线`插入关节2后，将导线通过电机上方剩余的导线孔穿入shell内
2. 关节3同上
3. 将4条延长线插入`linkage.lua`(长)结构件的导线孔内
4. 将延长线的两端分别通过关节2和关节3的法兰槽通孔穿入shell内，到电机顶部
5. 焊接所有导线
6. 使用`内六角螺丝钉M3*10`分别将关节2和关节3固定到`linkage.lua`(长)结构件，注意两关节轴要同向

## 6 安装上臂到关节1

材料：当前本体 1个、上臂 1个、`外六角螺丝M3*8` 6个、`十字平头螺丝M2*6` 2个

工具：`开口扳手5.5mm`、`十字螺丝刀`

将关节2安装到关节1上，步骤与关节1安装到底座相同

注意：关节1底部的M2螺丝难安装，此时安装顶部的即可

## 7 组装前臂

材料：DM4310关节(J4) 1个、`elbow.lua` 1个、`linkage.lua`(短) 1个、`内六角螺丝钉M3*10` 12个、`X30(2+2)线` 2个、导线若干、焊锡、热缩管或电工胶布

工具：`电烙铁`、`内六角扳手`

1. 将`X30(2+2)线`插入关节4后，将导线通过电机上方剩余的导线孔穿入shell内
2. 将4条延长线插入`linkage.lua`(短)结构件的导线孔内
3. 将延长线的一端分别通过关节4的法兰槽通孔穿入shell内，到电机顶部，另一端通过`elbow.lua`结构件的侧边方形孔穿出
4. 焊接所有导线
5. 使用`内六角螺丝钉M3*10`分别将关节4和`elbow.lua`结构件固定到`linkage.lua`(短)结构件，注意两个轴向

## 8 安装前臂到关节3

材料：当前本体 1个、前臂 1个、`外六角螺丝M3*8` 6个、`十字平头螺丝M2*6` 2个

工具：`开口扳手5.5mm`、`十字螺丝刀`

将`elbow`安装到关节3上，步骤与关节1安装到底座相同

## 9 安装关节5和关节6

材料：当前本体 1个、DM4310关节(J5 J6) 2个、`外六角螺丝M3*8` 12个、`十字平头螺丝M2*6` 4个

工具：`开口扳手5.5mm`、`十字螺丝刀`

1. 将关节5安装到关节4上，步骤与关节1安装到底座相同
2. 将关节6安装到关节5上，步骤与关节1安装到底座相同

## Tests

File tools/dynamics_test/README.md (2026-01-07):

# Mockway Robot - Inverse Dynamics Testing

基于 Pinocchio 库实现的 Mockway 机器人动力学逆解测试工程。

## 概述

本测试工程使用 Pinocchio（一个高效的刚体动力学库）来计算 Mockway 机器人的逆向动力学。

**逆向动力学（Inverse Dynamics）**：给定关节的位置、速度和加速度，计算所需的关节力矩。

数学表达式：
```
τ = M(q)·a + C(q,v)·v + g(q)
```

其中：
- `τ`: 关节力矩
- `M(q)`: 质量矩阵（惯性矩阵）
- `C(q,v)`: 科里奥利和离心力矩阵
- `g(q)`: 重力项
- `q`: 关节位置
- `v`: 关节速度
- `a`: 关节加速度

## 功能特性

本测试程序实现了以下功能：

### 离线仿真测试
1. **静态配置测试**：计算多个静态姿态下的重力补偿力矩
2. **轨迹跟踪测试**：沿正弦轨迹计算所需力矩并可视化
3. **动力学分解测试**：验证 M、C、g 各项的正确性
4. **可视化输出**：生成位置、速度、加速度和力矩的时间曲线图

### 实时力矩补偿控制（新增）
1. **实时重力补偿**：200Hz控制频率的重力力矩补偿
2. **完整动力学补偿**：基于加速度估计的全动力学补偿（惯性+科氏+离心+重力）
3. **加速度估计**：速度差分 + 低通滤波（截止频率可调）
4. **多模式切换**：支持运行时切换补偿模式
5. **配置系统**：支持YAML配置文件和命令行参数覆盖

## 安装依赖

### 方法 1：使用 pip 安装

```bash
cd tools/dynamics_test
pip install -r requirements.txt
```

### 方法 2：使用 conda 安装

```bash
# 创建新环境（推荐）
conda create -n mockway_dynamics python=3.8
conda activate mockway_dynamics

# 安装 Pinocchio
conda install pinocchio -c conda-forge

# 安装其他依赖
pip install numpy matplotlib
```

### 依赖说明

- **pin** (Pinocchio >=3.0.0): 刚体动力学计算库
- **numpy** (>=1.20.0): 数值计算
- **matplotlib** (>=3.3.0): 数据可视化

## 使用方法

### 运行动力学仿真测试

```bash
cd tools/dynamics_test
python inverse_dynamics_test.py
```

这将运行所有三个测试：
1. 静态配置测试
2. 动力学分解测试
3. 轨迹跟踪测试（并生成可视化图表）

### 运行实时力矩补偿控制（新增）

```bash
cd tools/dynamics_test
python realtime_torque_compensation.py
```

**前置要求**：
- 硬件连接：确保 USB-CAN 适配器已连接（默认COM9）
- 电机配置：
  - 关节1：DM-J4310-2EC 电机，CAN ID = 1
  - 关节2：DM4340 电机，CAN ID = 2
- 安全提示：首次运行前请确保机械臂处于安全位置

**功能模式**：
1. **重力补偿**：实时补偿重力力矩，机械臂可手动移动且感觉"失重"
2. **完整动力学补偿**：补偿重力、科里奥利力和离心力
3. **交互式控制**：可实时切换补偿模式和调整参数

### 输出示例

```
============================================================
Mockway Robot - Inverse Dynamics Testing with Pinocchio
============================================================

Model loaded: mockway_description
Number of joints: 2
Joint names: ['joint1', 'joint2']

============================================================
TEST 1: Static Configurations (Zero Velocity & Acceleration)
============================================================

Zero position:
  Joint positions: [0. 0.] deg
  Required torques: [0. 0.] Nm
  Gravity torques:  [0. 0.] Nm

Joint1 = 45°:
  Joint positions: [45. 0.] deg
  Required torques: [0.123 0.456] Nm
  Gravity torques:  [0.123 0.456] Nm

...
```

## 代码结构

```
dynamics_test/
├── inverse_dynamics_test.py         # 动力学仿真测试程序
├── realtime_torque_compensation.py  # 实时力矩补偿控制程序（新增）
├── requirements.txt                 # Python 依赖
├── README.md                        # 本文档
└── trajectory_results.png           # 生成的可视化结果（运行后生成）
```

## 核心 API

### MockwayDynamics 类

```python
class MockwayDynamics:
    def __init__(self, urdf_path)
    def compute_inverse_dynamics(self, q, v, a) -> tau
    def compute_mass_matrix(self, q) -> M
    def compute_coriolis(self, q, v) -> c
    def compute_gravity(self, q) -> g
    def get_end_effector_pose(self, q) -> (position, orientation)
```

### 使用示例

```python
from inverse_dynamics_test import MockwayDynamics
import numpy as np

# 初始化
dynamics = MockwayDynamics("path/to/mockway_description.urdf")

# 定义关节状态
q = np.array([0.5, 0.3])      # 位置 [rad]
v = np.array([0.1, -0.2])     # 速度 [rad/s]
a = np.array([1.0, 0.5])      # 加速度 [rad/s²]

# 计算所需力矩
tau = dynamics.compute_inverse_dynamics(q, v, a)
print(f"Required torques: {tau} Nm")

# 分别计算各项
M = dynamics.compute_mass_matrix(q)
c = dynamics.compute_coriolis(q, v)
g = dynamics.compute_gravity(q)
```

## 测试说明

### Test 1: 静态配置测试

测试在不同关节位置下的静态平衡（零速度、零加速度）。在此情况下，所需力矩应等于重力补偿力矩。

### Test 2: 动力学分解测试

验证逆动力学的正确性，通过对比：
- RNEA 算法（递归牛顿-欧拉算法）的结果
- 手动计算 M·a + C·v + g 的结果

两者应该一致。

### Test 3: 轨迹跟踪测试

沿正弦轨迹运动，计算每个时刻所需的关节力矩，并生成可视化图表：
- 关节位置曲线
- 关节速度曲线
- 关节加速度曲线
- 所需关节力矩曲线

## 参考资料

### Pinocchio 文档
- 官方网站: https://stack-of-tasks.github.io/pinocchio/
- GitHub: https://github.com/stack-of-tasks/pinocchio
- 教程: https://gepettoweb.laas.fr/doc/stack-of-tasks/pinocchio/master/doxygen-html/

### 逆向动力学相关
- [Rigid Body Dynamics Algorithms](https://link.springer.com/book/10.1007/978-1-4899-7560-7) by Roy Featherstone
- [Modern Robotics](http://hades.mech.northwestern.edu/index.php/Modern_Robotics) by Kevin M. Lynch and Frank C. Park

## 常见问题

**Q: 为什么在静态配置下力矩不为零？**

A: 即使机器人静止，重力仍会产生力矩。逆动力学计算的是维持给定状态所需的力矩，包括重力补偿。

**Q: 如何修改测试轨迹？**

A: 在 `test_trajectory_tracking()` 函数中修改 `amplitude` 和 `frequency` 参数即可。

**Q: 可以用于其他机器人吗？**

A: 可以，只需将 URDF 文件路径改为你的机器人模型即可。确保 URDF 包含正确的惯性参数。

**Q: 完整动力学模式下力矩输出抖动怎么办？**

A: 这通常是由于速度测量噪声导致的加速度估计不准确。可以尝试：
   1. 降低滤波器截止频率（如从5Hz降到2-3Hz）
   2. 检查电机速度反馈是否稳定
   3. 确保控制频率足够高（推荐≥200Hz）

**Q: 如何选择合适的滤波器截止频率？**

A: 根据运动速度选择：
   - 慢速示教（< 30°/s）：2-3 Hz，力矩输出更平滑
   - 正常运动（30-90°/s）：5 Hz（默认），平衡响应和噪声
   - 快速运动（> 90°/s）：8-10 Hz，减少相位延迟

   原则：速度越快，截止频率越高；要求越平滑，截止频率越低。

**Q: 为什么重力补偿和完整动力学补偿效果差别不大？**

A: 在慢速运动时，惯性力、科氏力和离心力相对较小，重力占主导。只有在快速运动或频繁加减速时，完整动力学补偿的优势才会明显。

## 实时力矩补偿控制详解

### RealtimeTorqueController 类

**新增功能**：实时动力学力矩补偿控制器

```python
class RealtimeTorqueController:
    def __init__(self, config: DynamicsTestConfig = None)
    def setup()                           # 初始化CAN和电机
    def enable_motors()                   # 使能电机
    def disable_motors()                  # 失能电机
    def start_control(mode="gravity")     # 启动控制循环
    def stop_control()                    # 停止控制循环
    def get_state_snapshot()              # 获取当前状态
    def shutdown()                        # 关闭控制器

    # 内部方法
    def _compute_filter_alpha(cutoff_freq)     # 计算滤波器系数
    def _apply_lowpass_filter(new, old, alpha) # 应用低通滤波
    def compute_compensation_torque(q, v, mode) # 计算补偿力矩（含加速度估计）
```

### 补偿模式说明

1. **"gravity"** - 重力补偿模式
   - 仅补偿重力力矩：`tau = g(q)`
   - 适用场景：手动示教、拖动示教
   - 效果：机械臂感觉"失重"，易于手动移动

2. **"full_dynamics"** - 完整动力学补偿模式
   - 补偿所有动力学项：`tau = M(q)·a + C(q,v)·v + g(q)`
   - 加速度估计：通过速度差分计算 `a = (v - v_prev) / dt`
   - 低通滤波：对加速度进行滤波以减少噪声（截止频率 5Hz）
   - 适用场景：需要精确动力学建模的控制，快速运动时的补偿
   - 效果：补偿重力、科里奥利力、离心力和惯性力

3. **"none"** - 无补偿模式
   - 不提供任何补偿
   - 用于对比测试

### 控制参数

- **control_rate**: 控制频率（默认 200 Hz）
- **kp**: MIT控制模式位置增益（默认 0.0，纯力矩控制）
- **kd**: MIT控制模式阻尼增益（默认 1.0）
- **accel_filter_cutoff**: 加速度低通滤波器截止频率（默认 5.0 Hz）
  - 降低频率（2-3 Hz）：更平滑的滤波，适合慢速运动
  - 提高频率（8-10 Hz）：更快的响应，适合快速运动

### 使用示例

```python
from realtime_torque_compensation import RealtimeTorqueController
from config_loader import load_config
import time

# 方法1：使用默认配置
controller = RealtimeTorqueController()

# 方法2：加载配置文件
config = load_config('config/dynamics_test.yaml')
controller = RealtimeTorqueController(config)

# 方法3：运行时调整滤波器参数
controller = RealtimeTorqueController()
controller._accel_filter_cutoff = 8.0  # 提高截止频率到8Hz
controller._accel_filter_alpha = controller._compute_filter_alpha(8.0)

try:
    # 设置并使能
    controller.setup()
    controller.enable_motors()

    # 启动完整动力学补偿（使用加速度估计）
    controller.start_control(mode="full_dynamics")

    # 运行一段时间
    time.sleep(10.0)

    # 获取当前状态
    state = controller.get_state_snapshot()
    print(f"位置: {state['q']} rad")
    print(f"速度: {state['v']} rad/s")
    print(f"力矩: {state['tau']} Nm")

finally:
    # 关闭
    controller.shutdown()
```

### 安全提示

⚠️ **重要安全注意事项**：

1. **首次运行**：确保机械臂处于安全位置，周围无障碍物
2. **紧急停止**：可随时按 Ctrl+C 停止程序
3. **力矩限制**：电机有力矩限制（Joint1: 9Nm, Joint2: 28Nm）
4. **监控温度**：长时间运行注意监控电机温度
5. **CAN连接**：确保CAN通信稳定，避免通信丢失

### 技术特性

- **实时性**：200Hz 控制频率，满足实时控制需求
- **线程安全**：使用锁机制保护共享状态
- **模块化设计**：动力学计算与电机控制解耦
- **多模式支持**：可在运行时切换补偿模式
- **加速度估计**：基于速度差分的实时加速度估计
- **噪声抑制**：一阶低通滤波器减少测量噪声影响

### 加速度估计与滤波技术

在完整动力学补偿模式下，系统使用以下方法估计关节加速度：

1. **速度差分**
   ```
   a_raw[k] = (v[k] - v[k-1]) / dt
   ```
   其中 `dt` 是控制周期（默认 5ms @ 200Hz）

2. **一阶低通滤波**
   ```
   a_filtered[k] = α · a_raw[k] + (1-α) · a_filtered[k-1]
   ```
   滤波器系数：`α = dt / (RC + dt)`，其中 `RC = 1 / (2π · fc)`

   默认截止频率 `fc = 5 Hz` 对应：
   - 3dB 衰减点在 5Hz
   - 相位延迟约 18ms
   - 有效抑制高频噪声（>20Hz）

3. **参数调优建议**
   - **慢速运动**（< 30°/s）：使用 2-3 Hz 截止频率，获得更平滑的力矩输出
   - **中速运动**（30-90°/s）：使用 5 Hz 截止频率（默认），平衡响应速度和噪声
   - **快速运动**（> 90°/s）：使用 8-10 Hz 截止频率，减少相位延迟

### 动力学补偿效果对比

| 补偿模式 | 补偿内容 | 适用场景 | 计算复杂度 |
|---|---|---|---|
| none | 无 | 对比测试 | 无 |
| gravity | 仅重力 g(q) | 手动示教、慢速运动 | 低 |
| full_dynamics | 惯性+科氏+离心+重力 | 快速运动、精确控制 | 中 |

## 许可

本测试工程遵循项目整体许可协议。

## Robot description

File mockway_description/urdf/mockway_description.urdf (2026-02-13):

<?xml version="1.0"?>
<robot name="mockway_description">

  <link name="base_link">
    <inertial>
      <mass value="0.097"/>
      <origin xyz="-0.000 -0.000 0.014" rpy="0 0 0"/>
      <inertia ixx="0.000049" iyy="0.000049" izz="0.000080" ixy="-0.000000" ixz="0.000000" iyz="0.000000"/>
    </inertial>
    <visual>
      <origin xyz="0 0 0" rpy="0 0 0"/>
      <geometry>
        <mesh filename="package://mockway_description/meshes/base_link.stl"/>
      </geometry>
      <material name="">
        <color rgba="0.127 0.301 0.847 1.000"/>
      </material>
    </visual>
    <collision>
      <origin xyz="0 0 0" rpy="0 0 0"/>
      <geometry>
        <mesh filename="package://mockway_description/meshes/base_link.stl"/>
      </geometry>
    </collision>
  </link>

  <joint name="joint1" type="revolute">
    <parent link="base_link"/>
    <child link="link1"/>
    <origin xyz="0.000 0.000 0.064" rpy="0.000 -0.000 0.000"/>
    <axis xyz="0 0 1"/>
    <limit lower="-6.280" upper="6.280" effort="9.000" velocity="3.140"/>
  </joint>

  <link name="link1">
    <inertial>
      <mass value="0.378"/>
      <origin xyz="0.000 -0.003 -0.005" rpy="0 0 0"/>
      <inertia ixx="0.000195" iyy="0.000176" izz="0.000204" ixy="-0.000000" ixz="-0.000000" iyz="0.000005"/>
    </inertial>
    <visual>
      <origin xyz="0 0 0" rpy="0 0 0"/>
      <geometry>
        <mesh filename="package://mockway_description/meshes/link1.stl"/>
      </geometry>
      <material name="">
        <color rgba="0.231 0.162 1.000 1.000"/>
      </material>
    </visual>
    <collision>
      <origin xyz="0 0 0" rpy="0 0 0"/>
      <geometry>
        <mesh filename="package://mockway_description/meshes/link1.stl"/>
      </geometry>
    </collision>
  </link>

  <joint name="joint2" type="revolute">
    <parent link="link1"/>
    <child link="link2"/>
    <origin xyz="0.000 0.000 0.000" rpy="1.571 -0.000 0.000"/>
    <axis xyz="0 0 1"/>
    <limit lower="-6.280" upper="6.280" effort="9.000" velocity="3.140"/>
  </joint>

  <link name="link2">
    <inertial>
      <mass value="0.568"/>
      <origin xyz="0.000 0.035 0.069" rpy="0 0 0"/>
      <inertia ixx="0.002661" iyy="0.000305" izz="0.002654" ixy="-0.000000" ixz="-0.000000" iyz="-0.000043"/>
    </inertial>
    <visual>
      <origin xyz="0 0 0" rpy="0 0 0"/>
      <geometry>
        <mesh filename="package://mockway_description/meshes/link2.stl"/>
      </geometry>
      <material name="">
        <color rgba="0.031 0.558 0.558 1.000"/>
      </material>
    </visual>
    <collision>
      <origin xyz="0 0 0" rpy="0 0 0"/>
      <geometry>
        <mesh filename="package://mockway_description/meshes/link2.stl"/>
      </geometry>
    </collision>
  </link>

  <joint name="joint3" type="revolute">
    <parent link="link2"/>
    <child link="link3"/>
    <origin xyz="0.000 0.190 0.000" rpy="0.000 -0.000 0.000"/>
    <axis xyz="0 0 1"/>
    <limit lower="-3.140" upper="3.140" effort="9.000" velocity="3.140"/>
  </joint>

  <link name="link3">
    <inertial>
      <mass value="0.488"/>
      <origin xyz="-0.000 0.131 0.006" rpy="0 0 0"/>
      <inertia ixx="0.001818" iyy="0.000257" izz="0.001814" ixy="0.000000" ixz="-0.000000" iyz="0.000079"/>
    </inertial>
    <visual>
      <origin xyz="0 0 0" rpy="0 0 0"/>
      <geometry>
        <mesh filename="package://mockway_description/meshes/link3.stl"/>
      </geometry>
      <material name="">
        <color rgba="1.000 0.212 0.080 1.000"/>
      </material>
    </visual>
    <collision>
      <origin xyz="0 0 0" rpy="0 0 0"/>
      <geometry>
        <mesh filename="package://mockway_description/meshes/link3.stl"/>
      </geometry>
    </collision>
  </link>

  <joint name="joint4" type="revolute">
    <parent link="link3"/>
    <child link="link4"/>
    <origin xyz="0.000 0.163 0.000" rpy="0.000 -0.000 0.000"/>
    <axis xyz="0 0 1"/>
    <limit lower="-6.280" upper="6.280" effort="3.000" velocity="3.140"/>
  </joint>

  <link name="link4">
    <inertial>
      <mass value="0.378"/>
      <origin xyz="0.000 0.005 0.068" rpy="0 0 0"/>
      <inertia ixx="0.000195" iyy="0.000204" izz="0.000176" ixy="0.000000" ixz="-0.000000" iyz="-0.000005"/>
    </inertial>
    <visual>
      <origin xyz="0 0 0" rpy="0 0 0"/>
      <geometry>
        <mesh filename="package://mockway_description/meshes/link4.stl"/>
      </geometry>
      <material name="">
        <color rgba="0.701 0.162 0.672 1.000"/>
      </material>
    </visual>
    <collision>
      <origin xyz="0 0 0" rpy="0 0 0"/>
      <geometry>
        <mesh filename="package://mockway_description/meshes/link4.stl"/>
      </geometry>
    </collision>
  </link>

  <joint name="joint5" type="revolute">
    <parent link="link4"/>
    <child link="link5"/>
    <origin xyz="0.000 0.000 0.071" rpy="-1.571 0.000 0.000"/>
    <axis xyz="0 0 1"/>
    <limit lower="-6.280" upper="6.280" effort="3.000" velocity="3.140"/>
  </joint>

  <link name="link5">
    <inertial>
      <mass value="0.378"/>
      <origin xyz="-0.000 -0.005 0.068" rpy="0 0 0"/>
      <inertia ixx="0.000195" iyy="0.000204" izz="0.000176" ixy="0.000000" ixz="0.000000" iyz="0.000005"/>
    </inertial>
    <visual>
      <origin xyz="0 0 0" rpy="0 0 0"/>
      <geometry>
        <mesh filename="package://mockway_description/meshes/link5.stl"/>
      </geometry>
      <material name="">
        <color rgba="0.061 0.223 0.456 1.000"/>
      </material>
    </visual>
    <collision>
      <origin xyz="0 0 0" rpy="0 0 0"/>
      <geometry>
        <mesh filename="package://mockway_description/meshes/link5.stl"/>
      </geometry>
    </collision>
  </link>

  <joint name="joint6" type="revolute">
    <parent link="link5"/>
    <child link="link6"/>
    <origin xyz="0.000 -0.039 0.071" rpy="1.571 -0.000 0.000"/>
    <axis xyz="0 0 1"/>
    <limit lower="-6.280" upper="6.280" effort="3.000" velocity="3.140"/>
  </joint>

  <link name="link6">
    <inertial>
      <mass value="0.016"/>
      <origin xyz="0.000 -0.000 -0.004" rpy="0 0 0"/>
      <inertia ixx="0.000003" iyy="0.000003" izz="0.000006" ixy="0.000000" ixz="0.000000" iyz="0.000000"/>
    </inertial>
    <visual>
      <origin xyz="0 0 0" rpy="0 0 0"/>
      <geometry>
        <mesh filename="package://mockway_description/meshes/link6.stl"/>
      </geometry>
      <material name="">
        <color rgba="0.527 0.527 0.527 1.000"/>
      </material>
    </visual>
    <collision>
      <origin xyz="0 0 0" rpy="0 0 0"/>
      <geometry>
        <mesh filename="package://mockway_description/meshes/link6.stl"/>
      </geometry>
    </collision>
  </link>

</robot>

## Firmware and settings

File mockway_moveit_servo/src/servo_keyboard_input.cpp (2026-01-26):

/*********************************************************************
 * Software License Agreement (BSD License)
 *
 *  Copyright (c) 2023, PickNik LLC
 *  All rights reserved.
 *
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
 *   * Redistributions of source code must retain the above copyright
 *     notice, this list of conditions and the following disclaimer.
 *   * Redistributions in binary form must reproduce the above
 *     copyright notice, this list of conditions and the following
 *     disclaimer in the documentation and/or other materials provided
 *     with the distribution.
 *   * Neither the name of PickNik LLC nor the names of its
 *     contributors may be used to endorse or promote products derived
 *     from this software without specific prior written permission.
 *
 *  THIS SOFTWARE IS PROVIDED BY THE COPYRIGHT HOLDERS AND CONTRIBUTORS
 *  "AS IS" AND ANY EXPRESS OR IMPLIED WARRANTIES, INCLUDING, BUT NOT
 *  LIMITED TO, THE IMPLIED WARRANTIES OF MERCHANTABILITY AND FITNESS
 *  FOR A PARTICULAR PURPOSE ARE DISCLAIMED. IN NO EVENT SHALL THE
 *  COPYRIGHT OWNER OR CONTRIBUTORS BE LIABLE FOR ANY DIRECT, INDIRECT,
 *  INCIDENTAL, SPECIAL, EXEMPLARY, OR CONSEQUENTIAL DAMAGES (INCLUDING,
 *  BUT NOT LIMITED TO, PROCUREMENT OF SUBSTITUTE GOODS OR SERVICES;
 *  LOSS OF USE, DATA, OR PROFITS; OR BUSINESS INTERRUPTION) HOWEVER
 *  CAUSED AND ON ANY THEORY OF LIABILITY, WHETHER IN CONTRACT, STRICT
 *  LIABILITY, OR TORT (INCLUDING NEGLIGENCE OR OTHERWISE) ARISING IN
 *  ANY WAY OUT OF THE USE OF THIS SOFTWARE, EVEN IF ADVISED OF THE
 *  POSSIBILITY OF SUCH DAMAGE.
 *********************************************************************/

/*      Title     : servo_keyboard_input.cpp
 *      Project   : moveit_servo
 *      Created   : 05/31/2021
 *      Author    : Adam Pettinger, V Mohammed Ibrahim
 */

#include <chrono>
#include <control_msgs/msg/joint_jog.hpp>
#include <geometry_msgs/msg/twist_stamped.hpp>
#include <moveit_msgs/srv/servo_command_type.hpp>
#include <rclcpp/executors/single_threaded_executor.hpp>
#include <rclcpp/rclcpp.hpp>
#include <signal.h>
#include <stdio.h>
#ifndef WIN32
#include <termios.h>
#include <unistd.h>
#else
#include <conio.h>
#endif

// Define used keys
namespace
{
constexpr int8_t KEYCODE_RIGHT = 0x43;
constexpr int8_t KEYCODE_LEFT = 0x44;
constexpr int8_t KEYCODE_UP = 0x41;
constexpr int8_t KEYCODE_DOWN = 0x42;
constexpr int8_t KEYCODE_PERIOD = 0x2E;
constexpr int8_t KEYCODE_SEMICOLON = 0x3B;
constexpr int8_t KEYCODE_1 = 0x31;
constexpr int8_t KEYCODE_2 = 0x32;
constexpr int8_t KEYCODE_3 = 0x33;
constexpr int8_t KEYCODE_4 = 0x34;
constexpr int8_t KEYCODE_5 = 0x35;
constexpr int8_t KEYCODE_6 = 0x36;
constexpr int8_t KEYCODE_7 = 0x37;
constexpr int8_t KEYCODE_Q = 0x71;
constexpr int8_t KEYCODE_R = 0x72;
constexpr int8_t KEYCODE_J = 0x6A;
constexpr int8_t KEYCODE_T = 0x74;
constexpr int8_t KEYCODE_W = 0x77;
constexpr int8_t KEYCODE_E = 0x65;
}  // namespace

// Some constants used in the Servo Teleop demo
namespace
{
const std::string TWIST_TOPIC = "/servo_node/delta_twist_cmds";
const std::string JOINT_TOPIC = "/servo_node/delta_joint_cmds";
const size_t ROS_QUEUE_SIZE = 10;
const std::string PLANNING_FRAME_ID = "base_link";
const std::string EE_FRAME_ID = "link6";
}  // namespace

// A class for reading the key inputs from the terminal
class KeyboardReader
{
public:
  KeyboardReader() : file_descriptor_(0)
  {
#ifndef WIN32
    // get the console in raw mode
    tcgetattr(file_descriptor_, &cooked_);
    struct termios raw;
    memcpy(&raw, &cooked_, sizeof(struct termios));
    raw.c_lflag &= ~(ICANON | ECHO);
    // Setting a new line, then end of file
    raw.c_cc[VEOL] = 1;
    raw.c_cc[VEOF] = 2;
    tcsetattr(file_descriptor_, TCSANOW, &raw);
#endif
  }
  void readOne(char* c)
  {
#ifndef WIN32
    int rc = read(file_descriptor_, c, 1);
    if (rc < 0)
    {
      throw std::runtime_error("read failed");
    }
#else
    *c = static_cast<char>(_getch());
#endif
  }
  void shutdown()
  {
#ifndef WIN32
    tcsetattr(file_descriptor_, TCSANOW, &cooked_);
#endif
  }

private:
  int file_descriptor_;
#ifndef WIN32
  struct termios cooked_;
#endif
};

// Converts key-presses to Twist or Jog commands for Servo, in lieu of a controller
class KeyboardServo
{
public:
  KeyboardServo();
  int keyLoop();

private:
  void spin();

  rclcpp::Node::SharedPtr nh_;

  rclcpp::Publisher<geometry_msgs::msg::TwistStamped>::SharedPtr twist_pub_;
  rclcpp::Publisher<control_msgs::msg::JointJog>::SharedPtr joint_pub_;
  rclcpp::Client<moveit_msgs::srv::ServoCommandType>::SharedPtr switch_input_;

  std::shared_ptr<moveit_msgs::srv::ServoCommandType::Request> request_;
  double joint_vel_cmd_;
  std::string command_frame_id_;
};

KeyboardServo::KeyboardServo() : joint_vel_cmd_(1.0), command_frame_id_{ "base_link" }
{
  nh_ = rclcpp::Node::make_shared("servo_keyboard_input");

  twist_pub_ = nh_->create_publisher<geometry_msgs::msg::TwistStamped>(TWIST_TOPIC, ROS_QUEUE_SIZE);
  joint_pub_ = nh_->create_publisher<control_msgs::msg::JointJog>(JOINT_TOPIC, ROS_QUEUE_SIZE);

  // Client for switching input types
  switch_input_ = nh_->create_client<moveit_msgs::srv::ServoCommandType>("servo_node/switch_command_type");
}

KeyboardReader input;

void quit(int sig)
{
  (void)sig;
  input.shutdown();
  rclcpp::shutdown();
  exit(0);
}

int main(int argc, char** argv)
{
  rclcpp::init(argc, argv);
  KeyboardServo keyboard_servo;

  signal(SIGINT, quit);

  int rc = keyboard_servo.keyLoop();
  input.shutdown();
  rclcpp::shutdown();

  return rc;
}

void KeyboardServo::spin()
{
  rclcpp::executors::SingleThreadedExecutor executor;
  executor.add_node(nh_);
  while (rclcpp::ok())
  {
    executor.spin_some();
  }
}

int KeyboardServo::keyLoop()
{
  char c;
  bool publish_twist = false;
  bool publish_joint = false;

  std::thread{ [this]() { return spin(); } }.detach();

  puts("Reading from keyboard");
  puts("---------------------------");
  puts("All commands are in the planning frame");
  puts("Use arrow keys and the '.' and ';' keys to Cartesian jog");
  puts("Use 1|2|3|4|5|6|7 keys to joint jog. 'r' to reverse the direction of jogging.");
  puts("Use 'j' to select joint jog. ");
  puts("Use 't' to select twist ");
  puts("Use 'w' and 'e' to switch between sending command in planning frame or end effector frame");
  puts("'Q' to quit.");

  for (;;)
  {
    // get the next event from the keyboard
    try
    {
      input.readOne(&c);
    }
    catch (const std::runtime_error&)
    {
      perror("read():");
      return -1;
    }

    RCLCPP_DEBUG(nh_->get_logger(), "value: 0x%02X\n", c);

    // // Create the messages we might publish
    auto twist_msg = std::make_unique<geometry_msgs::msg::TwistStamped>();
    auto joint_msg = std::make_unique<control_msgs::msg::JointJog>();

    joint_msg->joint_names.resize(6);
    joint_msg->joint_names = { "joint1", "joint2", "joint3", "joint4",
                               "joint5", "joint6" };

    joint_msg->velocities.resize(6);
    std::fill(joint_msg->velocities.begin(), joint_msg->velocities.end(), 0.0);
    // Use read key-press
    switch (c)
    {
      case KEYCODE_LEFT:
        RCLCPP_DEBUG(nh_->get_logger(), "LEFT");
        twist_msg->twist.linear.y = -0.5;
        publish_twist = true;
        break;
      case KEYCODE_RIGHT:
        RCLCPP_DEBUG(nh_->get_logger(), "RIGHT");
        twist_msg->twist.linear.y = 0.5;
        publish_twist = true;
        break;
      case KEYCODE_UP:
        RCLCPP_DEBUG(nh_->get_logger(), "UP");
        twist_msg->twist.linear.x = 0.5;
        publish_twist = true;
        break;
      case KEYCODE_DOWN:
        RCLCPP_DEBUG(nh_->get_logger(), "DOWN");
        twist_msg->twist.linear.x = -0.5;
        publish_twist = true;
        break;
      case KEYCODE_PERIOD:
        RCLCPP_DEBUG(nh_->get_logger(), "PERIOD");
        twist_msg->twist.linear.z = -0.5;
        publish_twist = true;
        break;
      case KEYCODE_SEMICOLON:
        RCLCPP_DEBUG(nh_->get_logger(), "SEMICOLON");
        twist_msg->twist.linear.z = 0.5;
        publish_twist = true;
        break;
      case KEYCODE_1:
        RCLCPP_DEBUG(nh_->get_logger(), "1");
        joint_msg->velocities[0] = joint_vel_cmd_;
        publish_joint = true;
        break;
      case KEYCODE_2:
        RCLCPP_DEBUG(nh_->get_logger(), "2");
        joint_msg->velocities[1] = joint_vel_cmd_;
        publish_joint = true;
        break;
      case KEYCODE_3:
        RCLCPP_DEBUG(nh_->get_logger(), "3");
        joint_msg->velocities[2] = joint_vel_cmd_;
        publish_joint = true;
        break;
      case KEYCODE_4:
        RCLCPP_DEBUG(nh_->get_logger(), "4");
        joint_msg->velocities[3] = joint_vel_cmd_;
        publish_joint = true;
        break;
      case KEYCODE_5:
        RCLCPP_DEBUG(nh_->get_logger(), "5");
        joint_msg->velocities[4] = joint_vel_cmd_;
        publish_joint = true;
        break;
      case KEYCODE_6:
        RCLCPP_DEBUG(nh_->get_logger(), "6");
        joint_msg->velocities[5] = joint_vel_cmd_;
        publish_joint = true;
        break;
      case KEYCODE_R:
        RCLCPP_DEBUG(nh_->get_logger(), "r");
        joint_vel_cmd_ *= -1;
        break;
      case KEYCODE_J:
        RCLCPP_DEBUG(nh_->get_logger(), "j");
        request_ = std::make_shared<moveit_msgs::srv::ServoCommandType::Request>();
        request_->command_type = moveit_msgs::srv::ServoCommandType::Request::JOINT_JOG;
        if (switch_input_->wait_for_service(std::chrono::seconds(1)))
        {
          auto result = switch_input_->async_send_request(request_);
          if (result.get()->success)
          {
            RCLCPP_INFO_STREAM(nh_->get_logger(), "Switched to input type: JointJog");
          }
          else
          {
            RCLCPP_WARN_STREAM(nh_->get_logger(), "Could not switch input to: JointJog");
          }
        }
        break;
      case KEYCODE_T:
        RCLCPP_DEBUG(nh_->get_logger(), "t");
        request_ = std::make_shared<moveit_msgs::srv::ServoCommandType::Request>();
        request_->command_type = moveit_msgs::srv::ServoCommandType::Request::TWIST;
        if (switch_input_->wait_for_service(std::chrono::seconds(1)))
        {
          auto result = switch_input_->async_send_request(request_);
          if (result.get()->success)
          {
            RCLCPP_INFO_STREAM(nh_->get_logger(), "Switched to input type: Twist");
          }
          else
          {
            RCLCPP_WARN_STREAM(nh_->get_logger(), "Could not switch input to: Twist");
          }
        }
        break;
      case KEYCODE_W:
        RCLCPP_DEBUG(nh_->get_logger(), "w");
        RCLCPP_INFO_STREAM(nh_->get_logger(), "Command frame set to: " << PLANNING_FRAME_ID);
        command_frame_id_ = PLANNING_FRAME_ID;
        break;
      case KEYCODE_E:
        RCLCPP_DEBUG(nh_->get_logger(), "e");
        RCLCPP_INFO_STREAM(nh_->get_logger(), "Command frame set to: " << EE_FRAME_ID);
        command_frame_id_ = EE_FRAME_ID;
        break;
      case KEYCODE_Q:
        RCLCPP_DEBUG(nh_->get_logger(), "quit");
        return 0;
    }

    // If a key requiring a publish was pressed, publish the message now
    if (publish_twist)
    {
      twist_msg->header.stamp = nh_->now();
      twist_msg->header.frame_id = command_frame_id_;
      twist_pub_->publish(std::move(twist_msg));
      publish_twist = false;
    }
    else if (publish_joint)
    {
      joint_msg->header.stamp = nh_->now();
      joint_msg->header.frame_id = PLANNING_FRAME_ID;
      joint_pub_->publish(std::move(joint_msg));
      publish_joint = false;
    }
  }

  return 0;
}

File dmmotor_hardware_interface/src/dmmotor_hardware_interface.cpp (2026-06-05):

#include "dmmotor_hardware_interface/dmmotor_hardware_interface.hpp"

// CAN通信相关头文件
#include <linux/can/raw.h>
#include <sys/socket.h>
#include <sys/ioctl.h>
#include <net/if.h>
#include <unistd.h>
#include <cstring>
#include <fcntl.h>    // O_NONBLOCK 定义在此
#include <termios.h>  // 串口配置

namespace dmmotor_hardware_interface
{

hardware_interface::CallbackReturn DMMototHardwareInterface::on_init(
  const hardware_interface::HardwareInfo & info)
{
  print_hardware_info(info, rclcpp::get_logger("DMMototHardwareInterface"));
  if (hardware_interface::SystemInterface::on_init(info) != hardware_interface::CallbackReturn::SUCCESS)
  {
    return hardware_interface::CallbackReturn::ERROR;
  }

  // 获取CAN接口类型(urdf: ros2_control->hardware->param : <param name="can_type">socketcan</param>)
  // 默认使用SocketCAN以保持向后兼容
  auto can_type_it = info_.hardware_parameters.find("can_type");
  if (can_type_it != info_.hardware_parameters.end()) {
    if (can_type_it->second == "usb_can" || can_type_it->second == "USB_CAN") {
      can_type_ = USB_CAN;
      RCLCPP_INFO(rclcpp::get_logger("DMMototHardwareInterface"), "Using USB-CAN adapter");
    } else {
      can_type_ = SOCKET_CAN;
      RCLCPP_INFO(rclcpp::get_logger("DMMototHardwareInterface"), "Using SocketCAN");
    }
  } else {
    can_type_ = SOCKET_CAN;
    RCLCPP_INFO(rclcpp::get_logger("DMMototHardwareInterface"), "Using SocketCAN (default)");
  }

  // 获取CAN接口名称(urdf: ros2_control->hardware->param : <param name="can_interface">can0</param>)
  // SocketCAN: can0, USB-CAN: /dev/ttyUSB0
  can_interface_ = info_.hardware_parameters.at("can_interface");

  // USB-CAN串口波特率（可选，默认921600）
  auto baudrate_it = info_.hardware_parameters.find("serial_baudrate");
  if (baudrate_it != info_.hardware_parameters.end()) {
    serial_baudrate_ = std::stoi(baudrate_it->second);
  }
  
  // 初始化电机列表
  motors_.resize(info_.joints.size());
  
  for (size_t i = 0; i < info_.joints.size(); i++)
  {
    // 关节参数(urdf: ros2_control->joint->param : <param name="can_id">0x02</param>)
    motors_[i].can_id = std::stoul(info_.joints[i].parameters.at("can_id"), nullptr, 16);
    motors_[i].kp = std::stod(info_.joints[i].parameters.at("kp"));
    motors_[i].kd = std::stod(info_.joints[i].parameters.at("kd"));
    
    // 检查是否为仿真电机
    auto sim_it = info_.joints[i].parameters.find("is_simulated");
    if (sim_it != info_.joints[i].parameters.end()) {
      motors_[i].is_simulated = (sim_it->second == "true");
    } else {
      motors_[i].is_simulated = false;  // 默认不是仿真电机
    }
    if (!motors_[i].is_simulated)
      is_sim_hardware = false;
    if (info_.joints[i].parameters.find("type") == info_.joints[i].parameters.end())
    {
      RCLCPP_ERROR(rclcpp::get_logger("DMMototHardwareInterface"), "param <type> is required");
      return hardware_interface::CallbackReturn::ERROR;
    }
    const auto type = static_cast<DM_Motor_Type>(std::stoi(info_.joints[i].parameters.at("type")));
    motors_[i].type = type;
    motors_[i].limit_param = limit_param[type];
    // 方向参数
    if (info_.joints[i].parameters.find("dir") == info_.joints[i].parameters.end()) {
      RCLCPP_ERROR(rclcpp::get_logger("DMMototHardwareInterface"), "param <dir> is required");
      return hardware_interface::CallbackReturn::ERROR;
    }
    const auto &dir = std::stoi(info_.joints[i].parameters.at("dir"));
    motors_[i].dir = (dir >= 0) ? 1.0 : -1.0;

    motors_[i].position = 0.0;
    motors_[i].velocity = 0.0;
    motors_[i].effort = 0.0;
    motors_[i].cmd_position = 0.0;
    motors_[i].cmd_velocity = 0.0;
    motors_[i].cmd_effort = 0.0;
  }

  for (const auto &motor : motors_)
  {
    RCLCPP_INFO(rclcpp::get_logger("DMMototHardwareInterface"), "type=%d, can_id=0x%03X, kp=%.2f, kd=%.2f, sim=%d",
                motor.type, motor.can_id, motor.kp, motor.kd, motor.is_simulated);
  }

  RCLCPP_INFO(rclcpp::get_logger("DMMototHardwareInterface"), "Is Simulate Hardware: %d", is_sim_hardware);
  RCLCPP_INFO(rclcpp::get_logger("DMMototHardwareInterface"),
              "Initialized with %zu motors on CAN interface %s",
              motors_.size(), can_interface_.c_str());

  return hardware_interface::CallbackReturn::SUCCESS;
}
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

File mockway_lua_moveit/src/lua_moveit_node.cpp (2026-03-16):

/**
 * lua_moveit_node.cpp
 *
 * LuaMoveItNode 类实现。
 * 将 MoveIt 和 MoveIt Servo 封装为 Lua API，支持：
 *   - 关节手动点动 (Joint Servo Jog)
 *   - 笛卡尔手动点动 (Cartesian Servo Twist)
 *   - 点到点规划执行 (PTP via MoveGroupInterface)
 *   - 直线运动 (Linear via computeCartesianPath)
 */

#include "mockway_lua_moveit/lua_moveit_node.hpp"

#include <moveit/planning_scene_interface/planning_scene_interface.hpp>
#include <geometry_msgs/msg/pose.hpp>
#include <geometry_msgs/msg/transform_stamped.hpp>
#include <tf2_geometry_msgs/tf2_geometry_msgs.hpp>
#include <tf2_eigen/tf2_eigen.hpp>
#include <tf2/exceptions.h>
#include <Eigen/Geometry>

#include <chrono>
#include <filesystem>
#include <future>
#include <sstream>
#include <thread>

using namespace std::chrono_literals;

// ─────────────────────────── 常量 ────────────────────────────────────────────
namespace defaults {
  const std::string PLANNING_GROUP = "mockway_group";
  const std::string EE_FRAME       = "link6";
  const std::string BASE_FRAME     = "base_link";
  const std::string TWIST_TOPIC    = "/servo_node/delta_twist_cmds";
  const std::string JOINT_TOPIC    = "/servo_node/delta_joint_cmds";
  const std::vector<std::string> JOINT_NAMES = {
    "joint1","joint2","joint3","joint4","joint5","joint6"
  };
}

// ─────────────────────────── 构造 ────────────────────────────────────────────
LuaMoveItNode::LuaMoveItNode()
: Node("lua_moveit_node",
       rclcpp::NodeOptions().automatically_declare_parameters_from_overrides(true))
{
  planning_group_ = declare_or_get("planning_group", defaults::PLANNING_GROUP);
  ee_frame_       = declare_or_get("ee_frame",       defaults::EE_FRAME);
  base_frame_     = declare_or_get("base_frame",     defaults::BASE_FRAME);

  twist_pub_ = create_publisher<geometry_msgs::msg::TwistStamped>(
    defaults::TWIST_TOPIC, rclcpp::QoS(10));
  joint_pub_ = create_publisher<control_msgs::msg::JointJog>(
    defaults::JOINT_TOPIC, rclcpp::QoS(10));

  servo_mode_client_ = create_client<moveit_msgs::srv::ServoCommandType>(
    "/servo_node/switch_command_type");

  // ── 订阅关节状态 ──────────────────────────────────────────────────────────
  joint_state_sub_ = create_subscription<sensor_msgs::msg::JointState>(
    "/joint_states", rclcpp::SensorDataQoS(),
    [this](const sensor_msgs::msg::JointState::SharedPtr msg) {
      std::lock_guard<std::mutex> lk(joint_cache_mutex_);
      cached_joint_names_     = msg->name;
      cached_joint_positions_ = msg->position;
    });

  // ── TF2 缓冲区（用于末端位姿查询） ──────────────────────────────────────
  tf_buffer_   = std::make_shared<tf2_ros::Buffer>(get_clock());
  tf_listener_ = std::make_shared<tf2_ros::TransformListener>(*tf_buffer_, this);

  RCLCPP_INFO(get_logger(), "LuaMoveItNode 初始化完成，planning_group=%s",
              planning_group_.c_str());
}

// ─────────────────────────── 公开方法 ────────────────────────────────────────
bool LuaMoveItNode::init_move_group()
{
  std::lock_guard<std::mutex> lk(mg_mutex_);
  if (move_group_) return true;
  if (mg_failed_)  return false;

  try {
    move_group_ = std::make_shared<moveit::planning_interface::MoveGroupInterface>(
      shared_from_this(), planning_group_);
    move_group_->setMaxVelocityScalingFactor(0.3);
    move_group_->setMaxAccelerationScalingFactor(0.1);
    move_group_->setPlanningTime(5.0);
    RCLCPP_INFO(get_logger(), "MoveGroupInterface 就绪，规划参考系: %s",
                move_group_->getPlanningFrame().c_str());
    return true;
  } catch (const std::exception& e) {
    RCLCPP_ERROR(get_logger(),
      "MoveGroupInterface 初始化失败（move_group 未运行？）: %s", e.what());
    move_group_ = nullptr;
    mg_failed_  = true;
    return false;
  }
}

int LuaMoveItNode::run_script(const std::string& script_path)
{
  if (!std::filesystem::exists(script_path)) {
    RCLCPP_ERROR(get_logger(), "Lua 脚本不存在: %s", script_path.c_str());
    return -1;
  }

  std::lock_guard<std::mutex> lua_lk(lua_mutex_);
  setup_lua_api();

  std::filesystem::path p(script_path);
  std::string dir = p.parent_path().string();
  lua_.script("package.path = package.path .. ';' .. '" + dir + "/?.lua'");

  RCLCPP_INFO(get_logger(), "执行 Lua 脚本: %s", script_path.c_str());
  try {
    lua_.script_file(script_path);
  } catch (const sol::error& e) {
    RCLCPP_ERROR(get_logger(), "Lua 错误: %s", e.what());
    return -1;
  }
  return 0;
}

int LuaMoveItNode::run_string(const std::string& code)
{
  if (code.empty()) {
    RCLCPP_ERROR(get_logger(), "Lua 代码字符串为空");
    return -1;
  }

  std::lock_guard<std::mutex> lua_lk(lua_mutex_);
  setup_lua_api();

  RCLCPP_INFO(get_logger(), "执行 Lua 字符串（%zu 字节）", code.size());
  try {
    lua_.script(code);
  } catch (const sol::error& e) {
    RCLCPP_ERROR(get_logger(), "Lua 错误: %s", e.what());
    return -1;
  }
  return 0;
}

std::pair<bool, std::string> LuaMoveItNode::run_string_captured(const std::string& code)
{
  if (code.empty()) return {false, "Empty script"};

  std::lock_guard<std::mutex> lua_lk(lua_mutex_);
  setup_lua_api();

  // 重定向 print 到字符串缓冲区
  std::string captured;
  lua_["print"] = [&captured](sol::variadic_args va) {
    std::ostringstream oss;
    bool first = true;
    for (const auto& v : va) {
      if (!first) oss << "\t";
      first = false;
      switch (v.get_type()) {
        case sol::type::number:
          if (v.is<int64_t>()) oss << v.as<int64_t>();
          else                 oss << v.as<double>();
          break;
        case sol::type::boolean: oss << (v.as<bool>() ? "true" : "false"); break;
        case sol::type::string:  oss << v.as<std::string>();                break;
        case sol::type::nil:     oss << "nil";                              break;
        default: oss << "[" << sol::type_name(v.lua_state(), v.get_type()) << "]";
      }
    }
    oss << "\n";
    captured += oss.str();
  };
#if 0
  RCLCPP_INFO(get_logger(), "HTTP 执行 Lua 字符串（%zu 字节）", code.size());
#else
  RCLCPP_INFO(get_logger(), "HTTP 执行 Lua 字符串\n%s", code.c_str());
#endif
  try {
    lua_.script(code);
    return {true, captured};
  } catch (const sol::error& e) {
    RCLCPP_ERROR(get_logger(), "Lua 错误: %s", e.what());
    return {false, std::string(e.what())};
  }
}

std::vector<double> LuaMoveItNode::get_joint_positions_raw()
{
  std::lock_guard<std::mutex> lk(joint_cache_mutex_);
  if (cached_joint_positions_.empty()) return {};

  // 按 joint1..joint6 顺序返回
  std::vector<double> result(defaults::JOINT_NAMES.size(), 0.0);
  for (size_t i = 0; i < defaults::JOINT_NAMES.size(); ++i) {
    for (size_t j = 0; j < cached_joint_names_.size(); ++j) {
      if (cached_joint_names_[j] == defaults::JOINT_NAMES[i]) {
        result[i] = cached_joint_positions_[j];
        break;
      }
    }
  }
  return result;
}
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

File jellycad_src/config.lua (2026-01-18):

--[[
Copyright (c) 2025. Li Jianbin. All rights reserved.
MIT License
JellyCAD version v0.3.10
Mockway Structure Config File
--]]
local config = {}
-- 装配
config.generate_step_file = false                                        -- true 运行combine.lua时生成所有零件的完整STEP文件，用于3D打印
-- 通用
config.r_motor = 57 / 2                                                  -- 电机直径57
config.r_motor_flank = 35 / 2                                            -- 电机法兰半径
config.r_screw_distribut = 50 / 2                                        -- 电机外壳螺丝分布半径
config.r_screw_motor_flank = 27 / 2                                      -- 电机法兰螺丝分布半径
config.h_motor_convex = 1                                                -- 电机凸台高度
config.thickness = 3                                                     -- 壳壁厚3
config.interspace = 0.2                                                  -- 电机壁与壳内壁的空隙0.2
config.r_outer = config.r_motor + config.interspace + config.thickness   -- 外壁半径
config.h_flank = 4                                                       -- 法兰高度(凹台高度)
config.t_flank_groove = 2                                                -- 法兰凹台壁厚
config.r_flank_groove = config.r_outer - config.t_flank_groove           -- 法兰凹台内壁半径
config.r_m2_hole = 1 + 0.1                                               -- M2螺丝通孔半径
config.r_m2d3_nut = 1.5 - 0.2                                            -- M2D3热熔螺母半径
config.r_m3d4_nut = 2 - 0.1                                              -- M3D4热熔螺母半径
config.r_m3_hole = 1.5 + 0.1                                             -- M3通孔半径
config.r_m3_head = 3                                                     -- M3平头空间半径
config.r_m2_tapping = 1.6 / 2                                            -- M2自攻螺丝孔
config.r_calib_slot = 1.7                                                -- 标定槽半径
config.h_calib_slot = 1                                                  -- 标定槽深度
config.r_flank = config.r_outer - config.t_flank_groove - 0.5            -- 法兰半径，预留0.5空间转动
config.r_flank_screw_head = 3.3                                          -- 法兰螺丝头通孔，用于通过M3外六角螺丝头
-- config.r_flank_screw_pos = config.r_flank - config.r_flank_screw_head - 2 -- 法兰螺丝位置半径
config.r_flank_screw_pos = config.r_screw_distribut                      -- 法兰螺丝位置半径
-- 基座
config.r_base_down = 45                                                  -- 基座下部半径
config.h_base_down = 8                                                   -- 基座下部高度
config.h_base_up = 16.6 + config.h_flank                                 -- 基座上部高度
config.h_base = config.h_base_down + config.h_base_up                    -- 基座总高度
config.r1_ellip = config.h_base_up                                       -- 切椭圆的半长轴
config.r2_ellip = config.r_base_down - config.r_outer                    -- 切椭圆的半短轴
config.z_base_m2_hole = config.h_base - config.h_flank / 2               -- 法兰侧边螺丝孔Z位置
config.r_m4_hole = 2.1                                                   -- 底座M4固定螺丝孔
config.r_m4_head = 4                                                     -- 底座M4固定螺丝头半径
config.r_base_vert_hole = 16                                             -- 竖直线孔半径
config.r_base_horiz_hole = 4                                             -- 水平线孔半径
config.z_base_horiz_hole = config.h_base_down + config.r_base_horiz_hole -- 水平线孔Z位置
config.r_base_screw_pos = 40                                             -- 底座螺丝位置半径
-- 外壳
config.r_shell_outer = config.r_outer                                    -- 外壳外壁半径
config.r_shell_inner = config.r_shell_outer - config.thickness           -- 外壳内壁半径
config.h_shell = 2 * config.r_outer                                      -- 外壳高度等于直径
config.r_shell_flank_hole = config.r_motor_flank + 1                     -- 外壳法兰孔半径，预留1的间隙
config.r_wire_hole = 12.5                                                -- 圆形通线孔半径
config.w_wire_solt = 2.4 * 2                                             -- 方形通线槽深度
config.l_wire_solt = 10                                                  -- 方形通线槽长度
config.w_can_plug = 16                                                   -- CAN插口宽度
config.w_ttl_plug = 10                                                   -- TTL插口宽度
config.h_plug = 17                                                       -- 插口高度
config.z_plug = config.thickness + 37                                    -- 插口底部Z位置
config.z_plug_top = config.z_plug + config.h_plug                        -- 插口顶部Z位置
-- 法兰
config.deg_slot = 18                                                     -- 螺丝槽角度
config.h_flank_reserve = 3.2;                                            -- 法兰预计抽空高度
-- 法兰颈部高度
config.h_flank_nick = (config.thickness - config.h_motor_convex) + config.h_flank_reserve;
config.h_flank_sum = config.h_flank_nick + config.h_flank; -- 法兰总高度
config.r_flank_outer = config.r_flank_groove - 0.5;        -- 法兰外壁半径，预留1mm空间转动
config.r_flank_inner = config.r_motor_flank;               -- 法兰本体半径
-- 连杆
config.r_arm_out = config.r_flank_screw_pos - 3.5 - 1;     -- 臂外径，预留螺母位，再额外预留1mm空间
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

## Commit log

2025-12-25 使用颜色显示松石绿(turquoise)
2025-12-25 法兰固定位置与电机上的半径一致
2025-12-26 加大基座孔
2025-12-26 更新README
2025-12-26 增加法兰模型
2025-12-27 修正法兰侧面热熔螺丝孔深度，应以法兰外壁为基准确认深度
2026-01-04 fix: update arm height configurations for upper and fore arms
    [config.lua]
2026-01-04 增加肘模型
2026-01-04 增加4340电机的支持，待测试
2026-01-04 串口输入改为串口选择，并且增加串口设备刷新功能
2026-01-04 增加串口设备描述的显示
2026-01-04 增加命令位置显示
2026-01-04 达秒C++例程中，4340最大速度是8
2026-01-05 将状态更新逻辑从"仅在使能时更新"改为"不论是否使能都更新"。
2026-01-05 修复插补线程在持有 control_lock 期间进行了大量计算导致界面阻塞问题
2026-01-05 tool-增加力矩控制-待测试
2026-01-06 重新整理组装
2026-01-06 装配-上臂增加电机
2026-01-06 装配-调整模型朝向
2026-01-06 修复重复show问题
2026-01-06 修复J3模组高度错误
2026-01-06 装配-增加组件质量
2026-01-07 实时力矩补偿控制程序(代测)
2026-01-07 基座模型-改为函数形式
2026-01-07 更新动力学测试说明
2026-01-08 完成连杆函数化，整理装配代码
2026-01-08 完成法兰模型函数化
2026-01-08 更新URDF
    [base_link.stl, link1.stl, link2.stl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]
2026-01-08 装配-增加上臂颜色
2026-01-08 增加前臂前部分
2026-01-08 完成前臂的其余部分
2026-01-09 装配-增加关节4模型
2026-01-09 增加手腕2-但是会导致模型导出有问题，待排查
2026-01-10 重构关节限制和URDF创建逻辑，使用局部变量提高代码可读性
2026-01-11 tools-动力学测试，修复关节位置读取不全
2026-01-11 tests-增加腕部的三个电机
2026-01-12 config-修复外部三个电机的类型
2026-01-12 更新动力学测试程序
2026-01-14 Fix error message in 配置Moveit.md
    Updated error message for controller configuration.
2026-01-14 Enhance DM Motor Hardware Interface with USB-CAN support and improve documentation
2026-01-14 Add simulation support for joints in DM Motor Hardware Interface
    [mockway_description.ros2_control.xacro]
2026-01-15 更新硬件接口程序
    [hardware_config_example.yaml, mockway_description.ros2_control.xacro]
2026-01-15 增加J2和J3刚度
    [mockway_description.ros2_control.xacro]
2026-01-15 关节kp增大，所有电机非仿真
    [mockway_description.ros2_control.xacro]
2026-01-16 README增加图片
2026-01-16 模型-增加模组后盖模型
2026-01-16 更新视频图标
2026-01-18 Add STEP file generation option for 3D printing in model files
2026-01-19 重力补偿取消电机阻尼
2026-01-21 Add images for motor GUI, torque compensation, and MoveIt! demo to README
2026-01-21 Update README and configuration paths for dynamics test
    - Improved README clarity by separating instructions into distinct lines.
    - Updated configuration file paths in `config_loader.py` and `realtime_torque_compensation.py` to reflect new structure.
    - Added new `dynamics_test.yaml` configuration file for torque compensation settings.
2026-01-26 Add initial implementation of mockway_moveit_servo package with configuration files and launch setup
    [servo_config.yaml]
2026-01-27 Add ArUco marker tracking functionality with launch files and scripts
    - Created launch files for real and simulated ArUco tracking:
    - `aruco_tracking.launch.py`: Launches the ArUco tracker node with configurable parameters.
    - `aruco_tracking_sim.launch.py`: Sets up Gazebo simulation with ArUco markers and camera.
    - Implemented the ArUco tracker in `aruco_tracker.py`:
    - Detects ArUco markers, applies pose filtering, and publishes pose and TF transforms.
    - Added scripts for generating ArUco markers and testing detection:
    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
    [model.sdf]
2026-01-28 Add Gazebo joint state bridge and update launch file for joint command bridging
    [mockway_gazebo.urdf.xacro]
2026-02-13 装配体增加后盖，更新URDF
    [link1.stl, link2.stl, link3.stl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]
2026-02-20 增加位置差值显示和更新逻辑，调整状态标签布局
2026-02-20 增加Kp和Kd的步进调整按钮，优化参数设置界面
2026-02-20 增加电机刚性，增加状态位置等于命令位置（备用）
    [mockway_description.ros2_control.xacro]
2026-02-27 降低关节的加速度和加加速度
    [joint_limits.yaml]
2026-02-28 增加lua节点，待测试
2026-03-11 修复编译问题
2026-03-11 修复package为nil
2026-03-12 lua-修复警告
2026-03-12 增强单轴点动日志记录，支持关节名称和索引的动态输出
2026-03-12 创建bringup包，将move_group+servo的启动文件作为bringup
2026-03-15 修复手动控制指令错误
2026-03-15 增加前端构建
2026-03-15 断开连接时应该时交叉图标
2026-03-15 修复速度百分比问题
2026-03-15 选择joint或cartesian标签时才发送切换servo模式
2026-03-15 放宽手动超时时间，避免发送频率过高
2026-03-15 脚本单位全部由m、rad改为mm、deg
2026-03-15 生成skill
2026-03-16 增加相对工具坐标系的运动指令
2026-03-16 bringup增加lua节点
2026-03-16 更新lua脚本示例
2026-03-16 删除robot_api脚本，更新脚本应用
2026-03-17 硬件-增加问题记录
2026-03-17 增加franka_hardware硬件参考
2026-03-17 增加新bringup调试
2026-03-18 手动发送频率降低，间隔为300ms
2026-03-18 增加with_rviz
2026-03-26 更新README内容
2026-03-26 更新电气拓扑
2026-03-30 新增装配指南文档，详细说明各组件的安装步骤和所需材料
2026-03-30 doc-组装指南-步骤1图片横向排列
2026-04-06 doc-组装指南-步骤2图片
2026-04-06 doc-组装指南-步骤2图片增加
2026-06-05 feat(复现): 确保能复现仿真
    - lua 运行时，分离npm install部分
    - moveit 仿真部分确保use- 以及hardware:=true 工作正常
    - 添加了 `Movelt2Ros.md` 以及 `Learn.md` 学习文档
    [joint_limits.yaml, mockway_description.ros2_control.xacro, mockway_description.urdf.xacro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]
2026-06-07 feat(gazebo): support gazebo simulation
    [mockway_description.ros2_control.xacro, mockway_description.urdf.xacro, mockway_world.sdf]
2026-06-07 feat(launch): 添加 gazebo_moveit 启动文件并更新 gazebo_bringup 配置
2026-06-08 feat(Mujoco): 基本联动实现
    - moveit和MujoCo联动实现
    - 使用跟随模式，而非actuator仿真
2026-06-08 feat(Mujoco): 统一时间
    - 统一MoveIt/RViz/bridge 时间
    - 更新readme
